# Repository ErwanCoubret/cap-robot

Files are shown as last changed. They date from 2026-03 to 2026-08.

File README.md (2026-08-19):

# CAP - ROBOT BODY

## OVERVIEW

Cap is the AI-powered assistant of [Flots app](https://flots.app). Its main purpose is to help users with their daily tasks and provide a friendly interface for interacting with the app.

The goal of this project is to give a physical form to Cap, allowing users to interact with it in a more natural and engaging way.

## RASPBERRY PI SETUP

From total scratch with a fresh Raspberry Pi OS light installation

### 1. Global updates and dependencies

```bash
sudo apt update && sudo apt upgrade -y
sudo apt install git-all -y
ssh-keygen -t ed25519 -C "your_email@example.com"
cat ~/.ssh/id_ed25519.pub
```

Copy the output of the last command and add it to your GitHub account (Settings > SSH and GPG keys > New SSH key)

Allow SSH access to the Raspberry Pi from your computer:

```sh
sudo systemctl enable --now ssh
```

SSH command on your remote computer:

```sh
ssh cap@192.168.10.127 # password: cap
```

### 2. Specific dependencies for the project

```bash
sudo apt install python3-pip python3-venv
```

#### Clone the repository

```bash
git clone
```

#### Install ai-camera dependencies

Read the [ai-camera README](./ai-camera/README.md) for instructions on how to set up the camera and load models.

#### Control eyes via serial

Read the [eyes README](./eyes/README.md) for instructions on how to control the eyes via serial protocol.

## Components

### Overview

```mermaid
flowchart TD
    RPiPSU[🔌 Raspberry Pi Power Supply]
    SPower[🔌 Servos Power Supply Adapter \nstored in head to centralize power distribution]

    RPiPSU --> HEAD
    SPower --> HEAD

    HEAD[== 🤖 HEAD ==]
    NECK[== 🦒 NECK ==]
    BODY[== 🧍 BODY ==]
    
    HEAD -- GPIO Control + Power --> NECK
    HEAD -- HDMI Video --> BODY
    HEAD -- Audio --> BODY
    
    subgraph HEAD
        RPi5[🖥️ Raspberry Pi 5\nmain control, face detection, interface, agent system]

        ESP32[🎮 ESP32]
        Cam[📷 AI Camera]
        Display1[📺 Rounded Display 1\n240x240]
        Display2[📺 Rounded Display 2\n240x240]

        MIC[🎤 Microphone]
    end
    
    subgraph NECK
        S1[⚙️ Servo 1 \nHorizontal]
        S2[⚙️ Servo 2 \nVertical]
    end
    
    subgraph BODY
        Disp[📺 Tactile Display]
        Spkr[🔊 Speaker]
    end
    
```

### List

#### HEAD

| Title | Description | Links |
|---|---|---|
| Raspberry Pi 5 8GB | Main computing unit | [Specs](./DOCS/RASPBERRY_PI_5.pdf) |
| Raspberry Pi AI Camera with Sony IMX500 | Vision module | [Specs](./DOCS/RASPBERRY_PI_CAMERA.pdf) |
| ESP32-WROOM-32 Development Board USB-C (NodeMCU-32S) | Microcontroller for eye displays | [Datasheet](./DOCS/esp32-wroom-32d_esp32-wroom-32u_datasheet_en.pdf) |
| 2 x GC9A01 1.28" TFT LCD Display Module | Eye displays, 240x240 pixels | [Datasheet](./DOCS/GC9A01%20DataSheet%20V1.1.pdf) |
| AGPTEK Microphone Module (AC02B Mini Lapel Microphone) | Audio input | - |

**Connections**

- USB-C to USB-C cable -> Raspberry Pi 5 Charging port
- Raspberry Pi Power Supply -> USB-C to USB-C cable, Female port
- USB-C to USB-A cable -> ESP32 USB-C port to Raspberry Pi USB-A port
- Wires to connect the GC9A01 displays to the ESP32

**Diagram**

```mermaid
flowchart TD
    RPi5[🖥️ Raspberry Pi 5]
    Camera[📷 AI Camera\nSony IMX500]
    ESP32[🎮 ESP32-WROOM-32]
    Display1[📺 GC9A01 Display 1\n240x240]
    Display2[📺 GC9A01 Display 2\n240x240]
    Mic[🎤 AC02B Microphone]
    RPiPSU[🔌 Raspberry Pi Power Supply]
    
    RPiPSU -- USB-C --> RPi5
    ESP32 -- USB-C to USB-A --> RPi5
    Camera -- CSI --> RPi5
    ESP32 -- GPIO/Wires --> Display1
    ESP32 -- GPIO/Wires --> Display2
    Mic -- USB/Audio --> RPi5
```

#### NECK

| Title | Description | Links |
|---|---|---|
| 2 x SG90 180° Servo Motor | Head movement control, GPIO controlled | - |
| Elegoo 545043 Breadboard Power Supply (5V/3.3V) | Power distribution, stored in head | [Specs](./DOCS/breadboard-datasheet.pdf) |
| AUKRU 5V/3A Power Supply Adapter | Power supply for breadboard | - |

**Connections:**
- Power Supply 5V/3A -> Breadboard Power Supply
- Wires to connect the SG90 servos to the Breadboard Power Supply and Raspberry Pi GPIO

**Diagram**

```mermaid
flowchart TD
    RPi5[🖥️ Raspberry Pi 5]
    Servo1[⚙️ SG90 Servo 1]
    Servo2[⚙️ SG90 Servo 2]
    BPS[🔌 Breadboard Power Supply\n545043]
    
    BPS -- 5V Power --> Servo1
    BPS -- 5V Power --> Servo2
    RPi5 -- GPIO Control --> Servo1
    RPi5 -- GPIO Control --> Servo2
```

#### BODY

| Title | Description | Links |
|---|---|---|
| MPI5008-5 inch 800x480 Tactile LCD Display Module | Main display with touch | [LCD Wiki](https://www.lcdwiki.com/5inch_HDMI_Displayn), [LCD Wiki Alt](https://www.lcdwiki.com/5inch_HDMI_Display) |
| Speaker (TBD) | Audio output | - |

**Connections**
- micro HDMI to HDMI cable -> Raspberry Pi micro HDMI port to Display Module HDMI port
- Wires to connect the Display Module (alimentation, tactile) to the Raspberry Pi GPIO

**Diagram**
```mermaid
flowchart TD
    RPi5[🖥️ Raspberry Pi 5]
    Display[📺 MPI5008-5in Display\n800x480]
    Speaker[🔊 Speaker\nTBD]
    
    RPi5 -- micro HDMI --> Display
    RPi5 -- GPIO/Touch --> Display
    RPi5 -- Audio --> Speaker
```

### 3D Models

TBD

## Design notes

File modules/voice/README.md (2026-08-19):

# Voice

Audio input/output for the robot. Mic is wired and verified; speaker is TBD
(see root [README.md](../../README.md)).

| Hardware | Role | Interface |
| --- | --- | --- |
| AGPTEK AC02B (lapel mic) | Audio input | USB |
| Speaker (TBD) | Audio output | not yet connected |

---

## 1. Verify the mic is detected

```bash
arecord -l
```

Expected: a USB card, e.g.

```
card 2: Device [USB PnP Sound Device], device 0: USB Audio [USB Audio]
```

If nothing lists, it's a USB/cable problem — nothing downstream can work.

List the ALSA device names actually usable with `-D`:

```bash
arecord -L
```

The one to use is `plughw:CARD=Device,DEV=0` (handles sample-rate/format
conversion; `hw:...` is stricter and can reject formats the app requests).

---

## 2. Check gain and mute state

```bash
amixer -c 2 contents
```

(replace `2` with the card number from `arecord -l`)

Reference state on this robot:

| Control | Value |
| --- | --- |
| `Mic Capture Switch` | `on` |
| `Mic Capture Volume` | `16` (max, 23.81dB) |
| `Auto Gain Control` | `on` |

If the switch is off or volume is 0, set it:

```bash
amixer -c 2 sset 'Mic' 16 unmute
```

---

## 3. Record a test clip

```bash
arecord -D plughw:CARD=Device,DEV=0 -f S16_LE -r 16000 -d 4 /tmp/mictest.wav
```

`-d 4` is the duration in seconds. Play it back on the Pi (if a speaker is
connected) with:

```bash
aplay /tmp/mictest.wav
```

### Check it actually captured signal, not silence

A clip can be zero-length-valid but pure noise floor if the mic is unplugged
at the connector, muted, or facing away. Check peak/RMS instead of trusting
the recording completed without error:

```bash
python3 test-codes/record_test.py --seconds 4
```

Talk or clap when it says to. Output:

```
peak=<n> rms=<n> (max=32767)
```

Peak below ~300 with someone actively talking near the mic means no usable
signal — check placement, gain (section 2), or cable, in that order.

---

## 4. Troubleshooting

| Symptom | Cause |
| --- | --- |
| `arecord -l` shows no card | USB mic unplugged or dead cable |
| `arecord` exits with `No such device` | Wrong `-D` value — re-check `arecord -L` |
| Recording succeeds but peak stays near 0 while talking | Mic muted (`Mic Capture Switch`) or gain at 0 |
| Peak is low but not zero, room is quiet | Normal — ambient noise floor, not a fault |
| `Device or resource busy` | Another process holds the device — `fuser /dev/snd/*` to find it |

---

## 5. Verified state

Measured on this robot (Raspberry Pi 5, `cap@192.168.10.127`):

- Mic enumerated: `card 2: Device [USB PnP Sound Device], device 0: USB Audio`
- `Mic Capture Switch: on`, `Mic Capture Volume: 16` (max), `Auto Gain Control: on`
- `arecord -D plughw:CARD=Device,DEV=0 ...` records without error, correct
  file size for the requested duration/rate
- Signal level pending a live talk/clap test near the mic to confirm
  capture, beyond ambient-noise-floor readings

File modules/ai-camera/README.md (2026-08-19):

# AI Camera IMX500

The Sony IMX500 is a camera module with an AI accelerator inside the sensor itself. The neural network runs on the sensor die, so inference costs the
Raspberry Pi almost no CPU: the Pi only reads the resulting tensors out of the
frame metadata.

https://docs.ultralytics.com/fr/integrations/sony-imx500

This directory holds the face tracker that drives the robot's eyes:
camera → face detection on the sensor → screen coordinates → ESP32 over serial.

```
IMX500 sensor            Raspberry Pi 5              ESP32 + GC9A01
[ YOLOv8n-face ]  --->  [ face_tracker.py ]  --->   [ eyes_serial.ino ]
   NPU, ~11 fps          decode + mapping            "x,y\n" @ 115200
```

---

## 1. Install

On the Raspberry Pi 5:

```bash
sudo apt update
sudo apt install -y python3-picamera2 imx500-all imx500-tools python3-opencv
sudo reboot
```

- `imx500-all` pulls in the sensor firmware and the stock model set
- `imx500-tools` provides `imx500-package`, needed to pack a custom model
- `python3-picamera2` is the capture and inference API
- `python3-opencv` is only needed for the visualiser, not for the tracker

`pyserial` ships with Raspberry Pi OS; check with `python3 -c "import serial"`.

> The `modlib` library (`aitrios-rpi-application-module-library`) is **not**
> required. It is a higher-level wrapper; everything here uses `picamera2`
> directly, which is already packaged and avoids a `--break-system-packages`
> pip install.

### Clone the repository on the Pi

```bash
git clone git@github.com:ErwanCoubret/cap-robot.git ~/cap-robot
```

---

## 2. Verify the hardware before running anything

Run these three checks in order. Each one isolates a different failure, so a
red result tells you exactly where to look.

**Camera detected on the CSI bus:**

```bash
rpicam-hello --list-cameras
```

Expected: `0 : imx500 [4056x3040 10-bit RGGB] (/base/axi/pcie@.../imx500@1a)`.
If the camera is missing, it is a cable or power problem — nothing downstream
can work.

**Sensor stack installed:**

```bash
dpkg -l | grep -E "imx500|picamera2"
```

Reference state on this robot:

| Package | Version |
| --- | --- |
| `imx500-all` | 1.12.0-1 |
| `imx500-firmware` | 0.FF23+3 |
| `imx500-models` | 1:1.0.0-1 |
| `imx500-tools` | 0~20241022+2-1+trixie |
| `python3-picamera2` | 0.3.37-1 |

**ESP32 present and writable:**

```bash
ls -l /dev/ttyUSB*
udevadm info -q property -n /dev/ttyUSB0 | grep ID_MODEL_FROM_DATABASE
groups | grep dialout
```

The board uses a CH340 bridge (`1a86:7523`), so it appears as `/dev/ttyUSB0`,
**not** `/dev/ttyACM0`. Your user must be in `dialout`; otherwise:

```bash
sudo usermod -aG dialout $USER   # log out and back in
```

### Check what the camera is actually looking at

Do this before debugging any "the model detects nothing" problem. A model that
returns zero detections because the camera faces a wall looks identical to a
broken model.

```bash
rpicam-jpeg -o /tmp/frame.jpg -t 2000
```

Then open `/tmp/frame.jpg` and confirm a face is in frame.

### Check the serial link on its own

This writes three positions straight to the ESP32, with no camera involved. The
pupil should jump left, right, then back to centre.

```bash
python3 - <<'EOF'
import serial, time
ser = serial.Serial("/dev/ttyUSB0", 115200, timeout=1, write_timeout=1)
time.sleep(2)                     # let the board finish rebooting
for p in ["60,120", "180,120", "120,120"]:
    ser.write((p + "\n").encode())
    print("sent", p)
    time.sleep(1.2)
ser.close()
EOF
```

If nothing moves, the fault is on the ESP32 side (wrong sketch flashed, wrong
baud rate), not on the camera side.

---

## 3. Put the face model on the sensor

The model is [YOLOv8n-face by lindevs](https://github.com/lindevs/yolov8-face),
already exported to IMX format in `models/yolov8n-face-lindevs_imx_model/`.

### Re-exporting from a `.pt` (only if you change the model)

```bash
yolo export model=models/yolov8n-face-lindevs.pt format=imx
```

This runs post-training quantisation and produces a folder containing
`packerOut.zip`, `labels.txt` and `dnnParams.xml`. Export on a desktop, not on
the Pi — it needs PyTorch and the compression toolkit.

`model-creation/model-compression.py` does the same quantisation by hand with
Sony's Model Compression Toolkit, using the photos in `model-creation/images/`
as the calibration set. It is only needed when the Ultralytics export gives
poor accuracy and the calibration data has to match the robot's real scene.

### Pack it into sensor firmware

`packerOut.zip` cannot be loaded directly — it has to become a `.rpk`:

```bash
cd ~/cap-robot/ai-camera/models/yolov8n-face-lindevs_imx_model
imx500-package -i packerOut.zip -o rpk
```

This writes `rpk/network.rpk` (3.0 MB). Check the memory report next to it:

```json
"Memory Usage": "7,06MB", "Total Memory Available On Chip": "8,00MB",
"Memory Utilization": "89%", "Fit In Chip": true
```

`Fit In Chip: false` means the model is too big for the sensor's 8 MB and will
never load, whatever you do afterwards.

`rpk/` is generated, not committed — regenerate it after every re-export.

---

## 4. Run the tracker

```bash
cd ~/cap-robot

python3 ai-camera/face_tracker.py                  # normal run, /dev/ttyUSB0
python3 ai-camera/face_tracker.py --verbose        # also print what is sent
python3 ai-camera/face_tracker.py --no-serial      # camera only, no ESP32
python3 ai-camera/face_tracker.py --threshold 0.6  # stricter detection
```

The first start uploads ~3 MB of network firmware into the sensor and takes
about 45 seconds, with a progress bar. Later starts reuse it and are fast.

`--no-serial` is the safe way to debug: it prints the coordinates it *would*
send, and never opens the serial port.

### Visualising what the robot sees

`face_tracker_visualizer.py` runs the same detection and drives the eye exactly
like the tracker, but also opens a window the size of the eye screen (240x240)
showing the camera view, the detected face and the position being sent.

```bash
cd ~/cap-robot/ai-camera
python3 face_tracker_visualizer.py --scale 2      # window doubled, eye driven
python3 face_tracker_visualizer.py --no-serial    # preview only
```

`q` or `Esc` quits. The window must be on the Pi's own display; over SSH,
prefix the command with `DISPLAY=:0`.

The preview is mirrored, like a selfie, which puts it in the same frame of
reference as the coordinates sent to the eye — so the red dot is drawn at the
transmitted position directly. If the dot sits on the face, the mapping is
correct. The grey circle marks how far the pupil can actually look: past it,
the firmware clamps to the edge.

Only one process can hold the IMX500 at a time. `Device or resource busy` on
startup means another run is still alive — wait for it, or `pkill -f
face_tracker`.

### Why the rates are capped

The sensor runs at 15 fps and the serial output at 20 Hz on purpose. The ESP32
reads one line per render loop; sending faster overflows its RX buffer and the
eye stutters or freezes. The firmware smooths motion on its side
(`SMOOTHING = 0.08`), so a higher rate would not look better anyway.

When no face has been visible for 1.5 s the tracker sends the centre position
once, then stays quiet until a face returns.

---

## 5. Reading the model output

This is the part that is not documented upstream and cost the most time, so it
is worth writing down.

The Ultralytics IMX export bakes NMS into the network. The sensor returns four
tensors, already sorted by confidence:

| Tensor | Shape | Meaning |
| --- | --- | --- |
| 0 | `(1, 300, 4)` | boxes |
| 1 | `(1, 300)` | scores |
| 2 | `(1, 300)` | class ids (always 0 — single class, `face`) |
| 3 | `(1, 1)` | number of valid detections |

Two traps, both confirmed by overlaying a box on a captured frame:

1. **Boxes are `[x0, y0, x1, y1]`** — not picamera2's usual `(y, x)` ordering.
2. **Boxes are absolute pixels in the model's square 640x640 input.** The
   camera stream is 640x480, so it is letterboxed with 80 px bars top and
   bottom. Subtract the padding before normalising:
   `img_y = box_y - 80`.

Consequently `imx500.convert_inference_coords()` **must not be used here**: it
assumes normalised boxes and returns six-digit garbage. `to_screen()` in
`face_tracker.py` removes the padding and normalises by hand.

The X axis is mirrored on purpose (`1.0 - cx`) so that when the person moves to
their right, the eye looks the same way they do.

---

## 6. Troubleshooting

| Symptom | Cause |
| --- | --- |
| Scores are all exactly `0.0` | No face in frame. Save a JPEG and look at it before suspecting the model. |
| Box values look plausible but scores are 0 | The box tensor shares its `l2Offset` with the input tensor, so it aliases image data. Trust the score, not the box. |
| Coordinates are six digits | `convert_inference_coords()` was used. See section 5. |
| Coordinates are sent but the pupil does not move | ESP32 side: wrong sketch flashed, or wrong baud rate. The sketch must be at 115200 and map to a 240x240 round screen. |
| `Permission denied` on `/dev/ttyUSB0` | User not in `dialout`. |
| Nothing on `/dev/ttyACM0` | Wrong device — the CH340 bridge enumerates as `/dev/ttyUSB0`. |
| `Fit In Chip: false` | Model too large for the sensor's 8 MB. |

---

## 7. Verified state

Measured on this robot (Raspberry Pi 5, `cap@192.168.10.127`):

- Camera enumerated: `imx500 [4056x3040 10-bit RGGB]`
- Face model packed to `network.rpk`, 89% chip memory, `Fit In Chip: true`
- Inference running at ~11 fps, **0.82 confidence on a live face, every frame**
- Serial writes accepted at 115200 baud on `/dev/ttyUSB0`
- Full loop confirmed end to end: camera → detection → mapping → ESP32, with
  the pupil following the face

## References

- [IMX500 converter documentation (Sony AITRIOS)](https://developer.aitrios.sony-semicon.com/en/docs/raspberry-pi-ai-camera/imx500-converter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)
- [Ultralytics IMX500 integration](https://docs.ultralytics.com/integrations/sony-imx500/#software-prerequisites)

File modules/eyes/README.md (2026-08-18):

# 👁️ Animated Eye Project (ESP32 + Round GC9A01 Display)

This project displays an animated eye (moving pupil + eyelid blinking) on a round GC9A01 TFT LCD screen, driven by an ESP32 microcontroller.

The render engine is optimized for maximum smoothness (60 FPS) with no flicker, while avoiding the memory crashes typical of the ESP32 by using a **Mini-Canvas**.

Two sketches are included:

* **`loop_eyes/`** — standalone demo, pupil cycles through fixed waypoints automatically.
* **`eyes_serial/`** — same render engine, but pupil target is driven live over serial (e.g. from a Raspberry Pi).

---

## 🛠️ Required Hardware

* **1x** ESP32 dev board (30-pin model)
* **1x** 1.28" round TFT LCD screen (GC9A01 driver)
* Jumper wires

---

## 🔌 Wiring (Pinout)

To guarantee max display speed, we use the ESP32's **Hardware SPI**. The screen pins must be connected to the board's dedicated hardware pins:

| GC9A01 Screen Pin | ESP32 Pin (Silkscreen) | Function |
| :--- | :--- | :--- |
| **VCC** | **3V3** | Power (3.3V) |
| **GND** | **GND** | Ground |
| **SCL / SCK** | **D18** | SPI Clock (Hardware SPI) |
| **SDA / MOSI** | **D23** | SPI Data (Hardware SPI) |
| **DC** | **D2** | Data / Command |
| **CS** | **D5** | Chip Select |
| **RST / RES** | **D4** | Reset |
| **BLK / BL** | **3V3** | Backlight (*Required — screen stays black without it*) |

---

## 💻 Setup & Requirements (Arduino IDE)

1. **Board configuration:** In Arduino IDE, select `Tools` > `Board` > **ESP32 Dev Module**.
2. **Required libraries:** Open the Library Manager (`Ctrl+Shift+I` or `Sketch > Include Library > Manage Libraries`) and install:
   * **Adafruit GFX Library**
   * **Adafruit GC9A01A**

---

## 🧠 How the Code Works

* **Hardware SPI:** By declaring only 3 pins (`TFT_CS`, `TFT_DC`, `TFT_RST`) in the display constructor, the ESP32 is forced to use its ultra-fast hardware SPI link (wired to pins D18 and D23).
* **The Mini-Canvas (128x128):** Instead of saturating RAM with a full 240x240 pixel buffer (which causes `StoreProhibited` crashes), a local 32 KB buffer is used around the pupil to erase and redraw movement with zero flicker and no trailing artifacts.
* **Async timers (`millis()`):** The code has no blocking `delay()`. Pupil movement and eyelid blinking run in parallel on independent time intervals.

---

## 📡 Serial Protocol (`eyes_serial`)

Send target pupil coordinates as text over serial, one pair per line:

```
<x>,<y>\n
```

* `x`, `y` are screen coordinates (center is `120,120`).
* If the point falls outside the eye radius, it's automatically clamped back onto the boundary.
* Baud rate: **115200**. At this rate the serial link is not the bottleneck — the SPI render loop is — so 115200 is plenty even for a Raspberry Pi pushing updates at 60-100 Hz.

### Testing from a Raspberry Pi

Find the ESP32's serial port first:

```bash
ls /dev/ttyUSB* /dev/ttyACM*
```

**Option 1 — `screen` (quick, interactive)**
```bash
screen /dev/ttyUSB0 115200
```
Type `120,150` + Enter to send a target. Exit with `Ctrl-A` then `k`, confirm `y`.

**Option 2 — `minicom` (nicer UI)**
```bash
sudo apt install minicom
minicom -D /dev/ttyUSB0 -b 115200
```
Quit with `Ctrl-A` then `X`.

**Option 3 — Python + pyserial (scripted test loop)**
```bash
pip install pyserial
python3 -c "
import serial, time
s = serial.Serial('/dev/ttyUSB0', 115200, timeout=1)
time.sleep(2)  # wait for ESP32 reset after port open
while True:
    s.write(b'120,150\n')
    time.sleep(1)
    s.write(b'60,90\n')
    time.sleep(1)
"
```

> Opening the serial port resets the ESP32 (DTR toggle) — expect a ~1-2s delay before it's ready. It prints `Systeme pret !` once initialized if you read the port back.

---

## ⚙️ Customization

Key parameters can be changed directly in the source code:

* **Colors (RGB565 format):**
  * `COLOR_WHITE` (`0xFFFF`): background / eyeball.
  * `COLOR_PUPIL` (`0x2169`): pupil color (`#232B49`).
  * `COLOR_EYELID` (`0x633F`): eyelid color (`#615FFF`).
* **Animation variables:**
  * `PUPIL_RADIUS`: pupil size (e.g. `60`).
  * `SMOOTHING`: glide smoothness (e.g. `0.08` for a slow, soft movement).
  * `BLINK_INTERVAL`: time between each blink (e.g. `1600` ms).
  * `DELAY_BETWEEN_MOVES` *(loop_eyes only)*: pause between each automatic waypoint change.

---

## 🆘 Troubleshooting

* **Screen stays black:** Check that the **BLK** pin is connected to **3.3V** and that the SPI lines (D18 and D23) are correct.
* **Port-related compile error:** Make sure **ESP32 Dev Module** is selected under Arduino board types.
* **No response from `eyes_serial`:** Confirm the baud rate matches on both ends (115200) and that you're writing to the correct `/dev/ttyUSB*`/`/dev/ttyACM*` device.

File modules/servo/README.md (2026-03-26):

# Servo-motor control

Related info for the servo-motor control module.

## Hardware setup

The servo-motor is connected to the Raspberry Pi 5 as follows:

- **GPIO Pin 18** (6th pin from the top left) is used for the PWM signal to control the servo.
- The servo's power and ground are connected to the appropriate pins on the Raspberry Pi (usually 5V and GND).

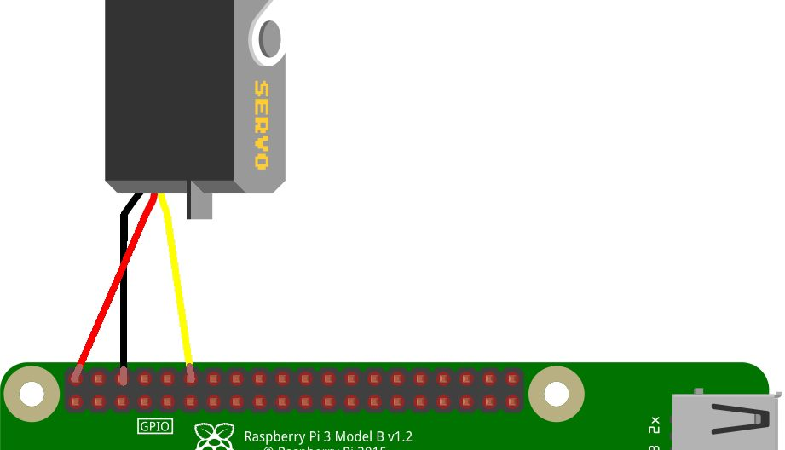
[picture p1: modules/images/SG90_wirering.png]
Servo Wiring Diagram


Source https://raspberry-pi.fr/servomoteur-raspberry-pi/ for more details on the wiring and setup

## Extreme values

With the following code, it is necessary to respect the extreme values of the servo-motor, otherwise it may be damaged.

`MAX_POS=0` and `MIN_POS=-1.8` are the limits of the servo-motor's range of motion.

```python
def set_pos(p):
  if p < -1.8 or p > 0:
    print("Value out of range [-1.8, 0]. Rejected to protect the hardware.")
    return

  # p ranges from -1.8 (left) to 0 (right)
  width = 1500 + (p * 500)

  # 1. Send PWM signal to move the servo
  lgpio.tx_pwm(h, GPIO_PIN, 50, (width / 20000.0) * 100.0)
  
  # 2. Wait for the servo to physically reach its destination
  time.sleep(0.5) 
  
  # 3. Cut the signal to prevent jitter
  lgpio.tx_pwm(h, GPIO_PIN, 0, 0)
```

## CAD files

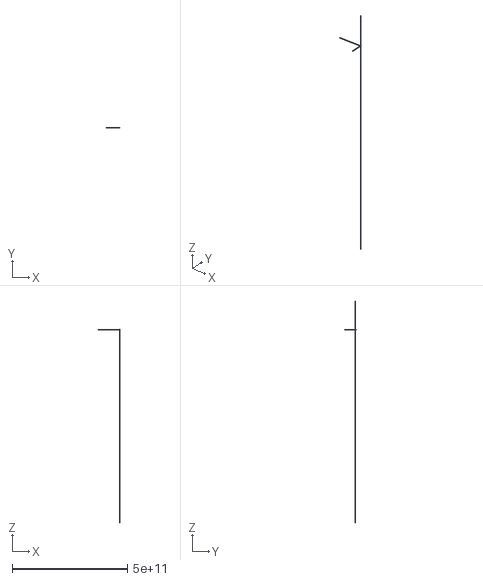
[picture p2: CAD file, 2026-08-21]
cap-3d-body/yeux mecatronic/Reference/Complete Model.stl
94940546112.0 x 50519834624.0 x 961114644480.0

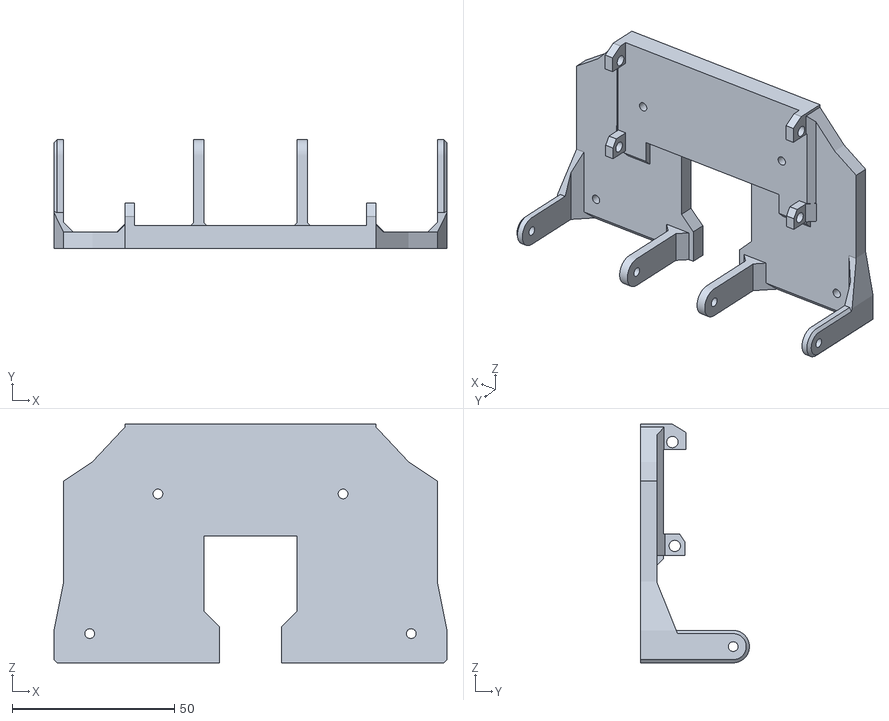
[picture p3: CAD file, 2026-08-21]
cap-3d-body/yeux mecatronic/Stl Files/Main Base.stl
121.0 x 33.5 x 73.5

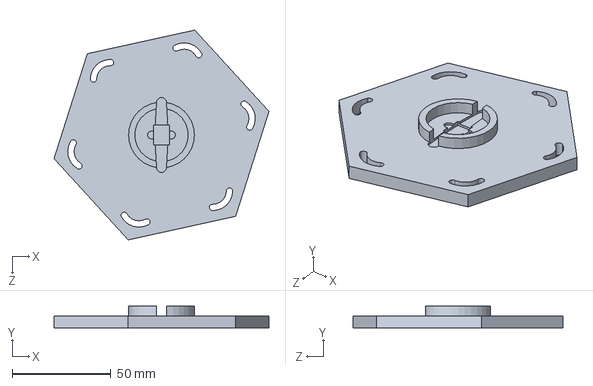
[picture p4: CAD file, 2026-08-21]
cap-3d-body/Cap/ancienne piece/socle coup.SLDPRT
109.0 x 11.0 x 106.4 mm

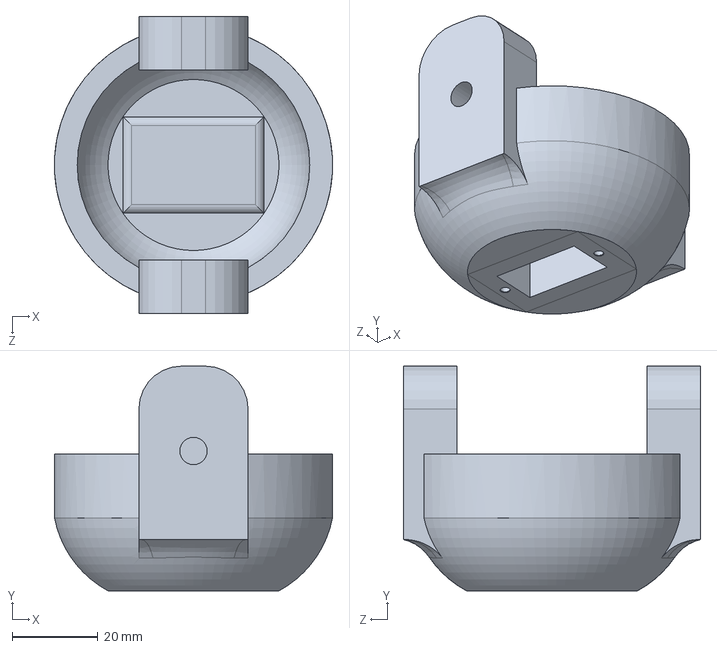
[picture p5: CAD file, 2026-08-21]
cap-3d-body/Cap/Cap VF/coup mobile lie corps.SLDPRT
64.9 x 52.5 x 69.5 mm

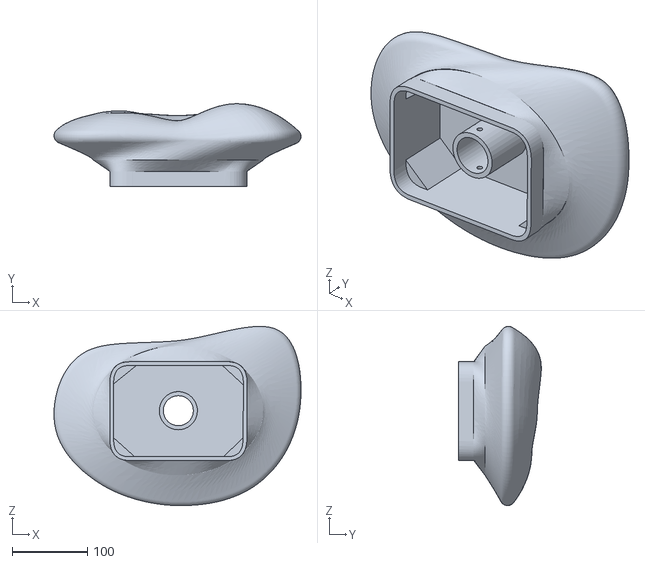
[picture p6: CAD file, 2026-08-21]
cap-3d-body/projet en stl/chapeau.STL
329.1 x 110.1 x 238.8

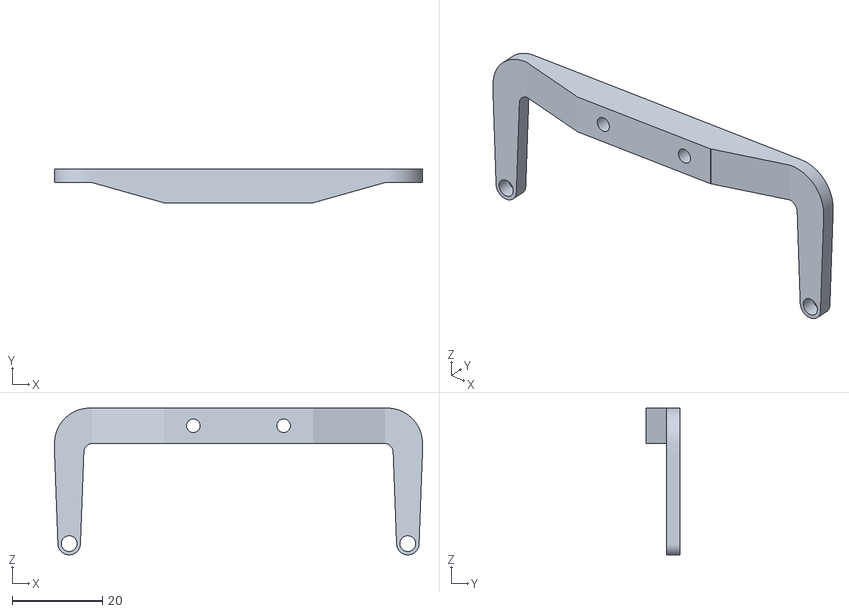
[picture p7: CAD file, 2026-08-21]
cap-3d-body/yeux mecatronic/Stl Files/Eye Holder.stl
81.5 x 7.53 x 32.5

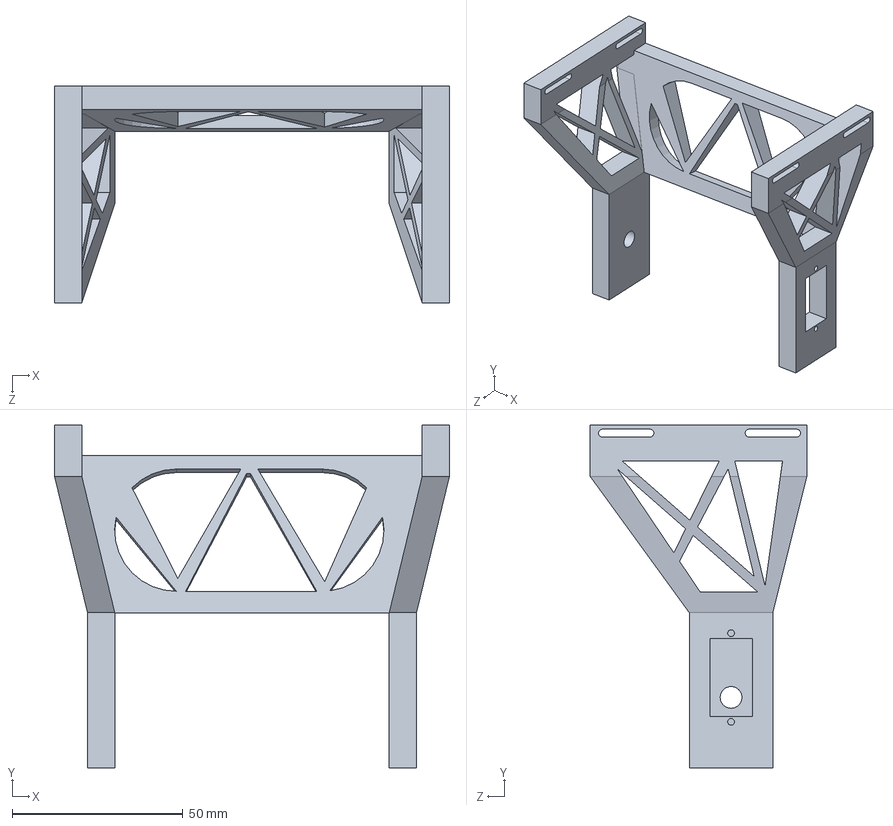
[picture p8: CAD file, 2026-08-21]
cap-3d-body/Cap/ancienne piece/coup mobile 2.SLDPRT
115.8 x 100.5 x 63.6 mm

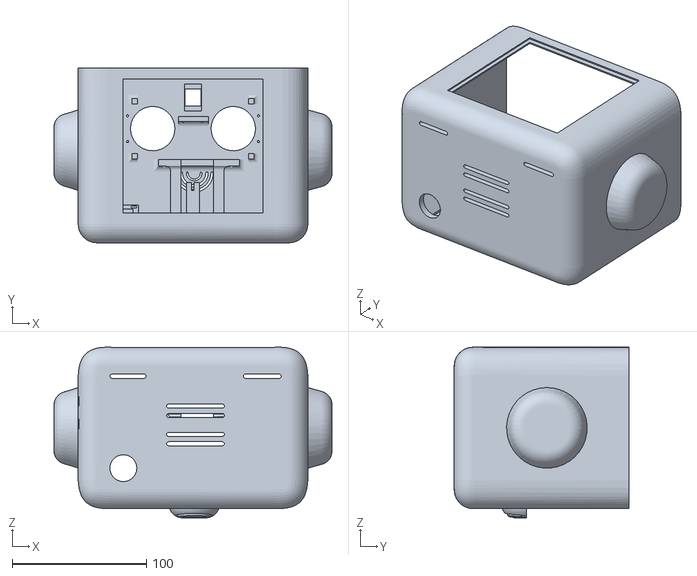
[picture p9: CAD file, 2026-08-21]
cap-3d-body/projet en stl/tete v2.STL
207.0 x 130.0 x 127.1

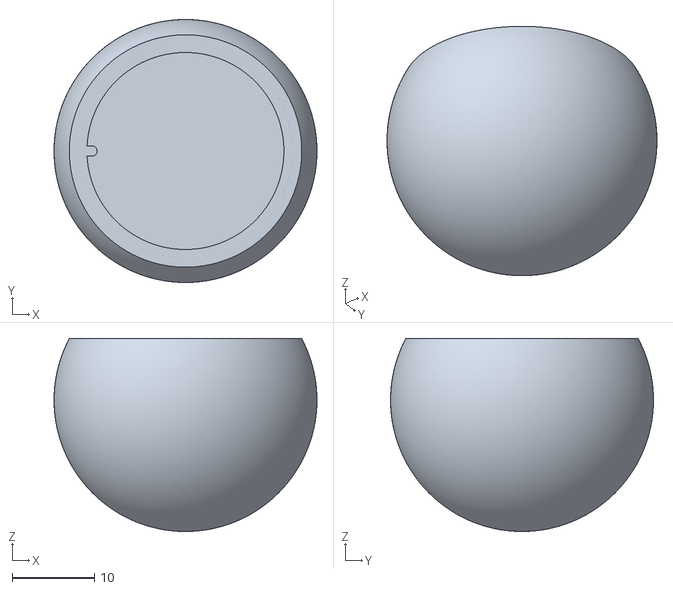
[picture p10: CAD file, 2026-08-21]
cap-3d-body/yeux mecatronic/Stl Files/PlaceHolder Eye (x2).stl
32.0 x 32.0 x 23.5

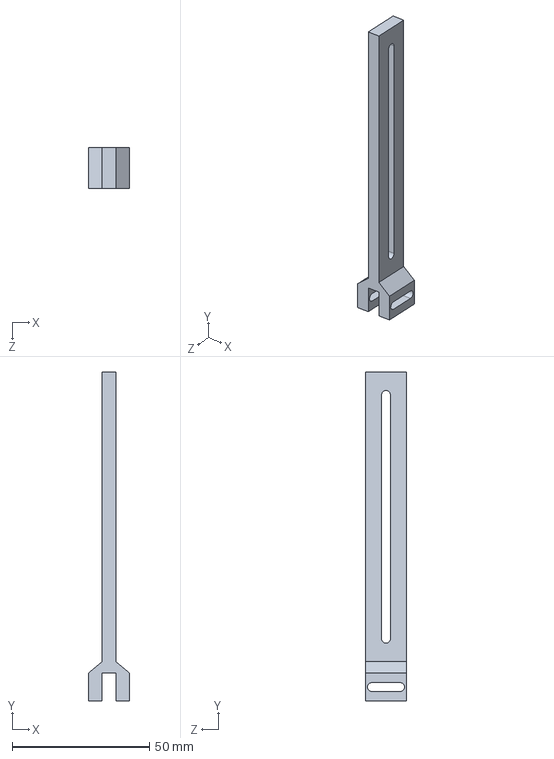
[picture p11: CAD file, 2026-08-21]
cap-3d-body/Cap/ancienne piece/raille x2.SLDPRT
15.0 x 120.0 x 15.0 mm

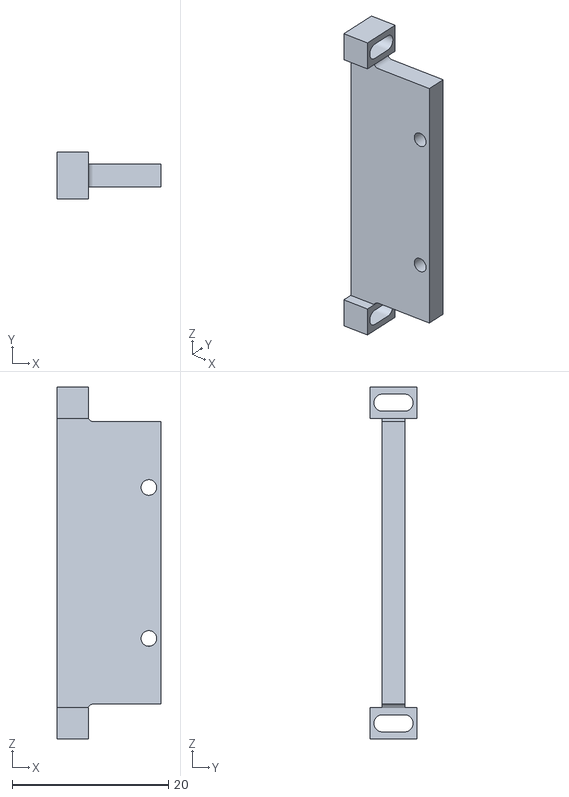
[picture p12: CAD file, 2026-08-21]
cap-3d-body/projet en stl/piece fixe oeuil x2.STL
13.3 x 6.00 x 45.0

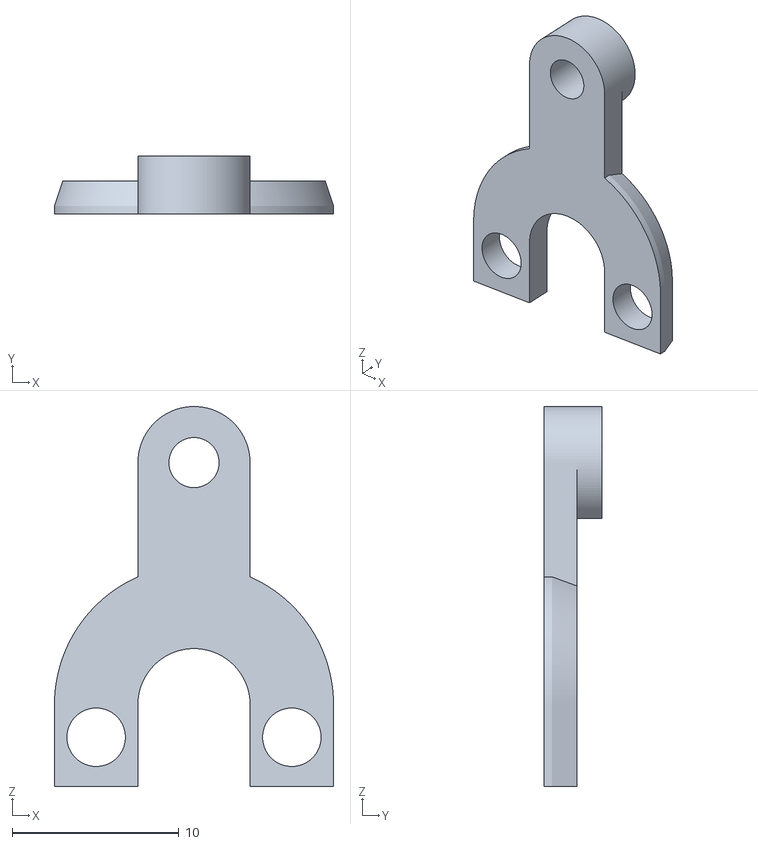
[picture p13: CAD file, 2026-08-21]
cap-3d-body/yeux mecatronic/Stl Files/Fork (x2).stl
16.7 x 3.50 x 22.8

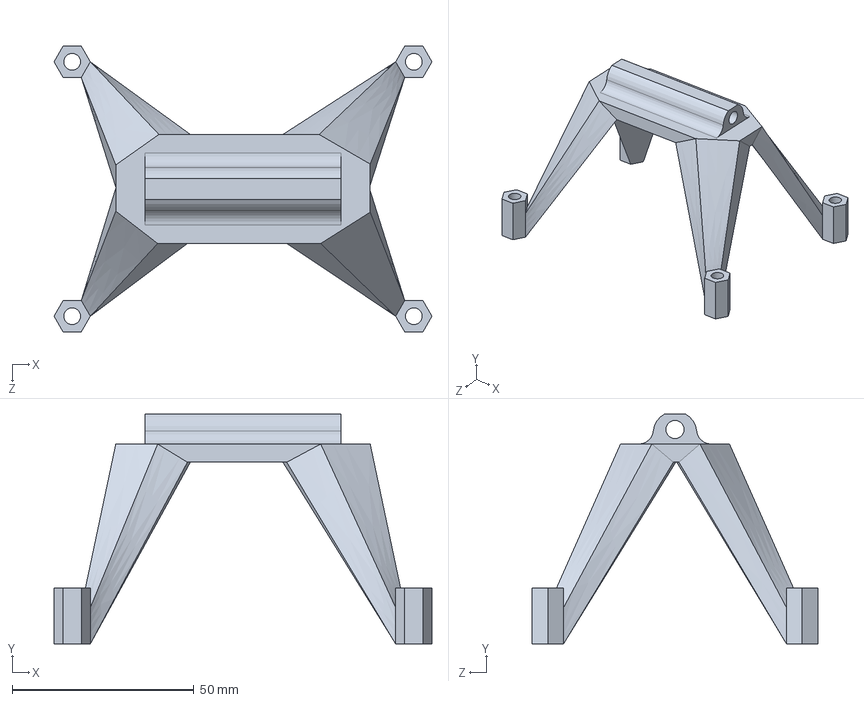
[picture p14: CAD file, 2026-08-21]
cap-3d-body/Cap/ancienne piece/piece fixe ecran 1.SLDPRT
104.0 x 63.3 x 78.7 mm

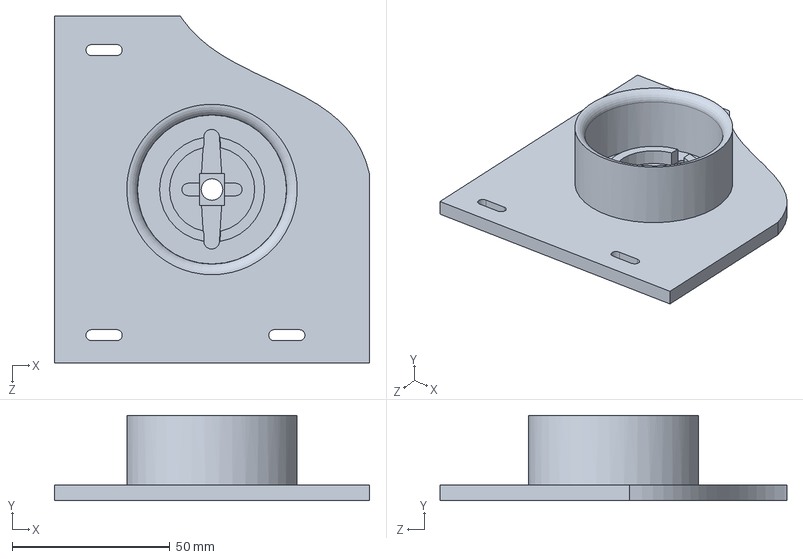
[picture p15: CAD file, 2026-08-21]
cap-3d-body/Cap/Cap VF/socle corps vers coup.SLDPRT
100.0 x 27.0 x 110.0 mm

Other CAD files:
cap-3d-body/Cap/Cap VF/chapeau.SLDPRT
cap-3d-body/Cap/Cap VF/tete.SLDPRT
cap-3d-body/projet en stl/coup mobile 2 version court.STL
cap-3d-body/Cap/ancienne piece/corps cap 1.SLDPRT
cap-3d-body/Cap/Cap VF/Porte tete.SLDPRT
cap-3d-body/Cap/Cap VF/corps cap V2.SLDPRT
cap-3d-body/Cap/Cap VF/coup mobile lie tete.SLDPRT
cap-3d-body/Cap/Cap VF/piece fixe oeuil.SLDPRT
cap-3d-body/Cap/Cap VF/porte corps.SLDPRT
cap-3d-body/Cap/Cap VF/socle tete vers coup.SLDPRT
cap-3d-body/Cap/ancienne piece/piece fixe ecran 2.SLDPRT
cap-3d-body/Cap/ancienne piece/tete 1.SLDPRT
cap-3d-body/projet en stl/corps cap 1.STL
cap-3d-body/projet en stl/corps cap V2 la bonne.STL
cap-3d-body/projet en stl/coup mobile 2 version court et ameliorer en largeur.STL
cap-3d-body/projet en stl/coup mobile 1.STL
cap-3d-body/projet en stl/piece fixe ecran 1.STL
cap-3d-body/projet en stl/piece fixe ecran 2.STL
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

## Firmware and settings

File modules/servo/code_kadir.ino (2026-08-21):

/*
 * ============================================================
 *  TEST SERVOS SG90 - Cou de robot (YAW + PITCH)
 *  Carte : Arduino Nano (ATmega328P)
 *  Moniteur série : 115200 bauds, fin de ligne "Nouvelle ligne"
 * ============================================================
 *
 *  CABLAGE
 *    Servo YAW   : signal -> D9   | Vcc -> +5V externe | GND -> GND
 *    Servo PITCH : signal -> D10  | Vcc -> +5V externe | GND -> GND
 *    IMPORTANT : la masse (GND) de l'alim externe DOIT etre reliee
 *    au GND du Nano (masse commune), sinon le signal n'est pas vu.
 *
 *  COMMANDES (taper dans le moniteur serie puis Entree)
 *    y120        -> place le YAW a 120 deg
 *    p60         -> place le PITCH a 60 deg
 *    c           -> retour au centre memorise
 *    z           -> definit la position ACTUELLE comme nouveau centre
 *    s           -> balayage lent min <-> max (test mecanique)
 *    l y 30 150  -> change les butees du yaw (min=30, max=150)
 *    l p 40 140  -> change les butees du pitch
 *    d           -> detache les servos (plus de couple, on peut bouger a la main)
 *    a           -> rattache les servos
 *    ?           -> affiche l'etat courant (a recopier dans le code)
 * ============================================================
 */

#include <Servo.h>

// ---------- Configuration ----------
const uint8_t PIN_YAW   = 8;
const uint8_t PIN_PITCH = 7;

const int STEP_DELAY = 15;   // ms par degre : plus grand = mouvement plus lent

struct Limits { int minDeg; int maxDeg; int center; };

// Valeurs de depart PRUDENTES : on evite 0 et 180 tant que la mecanique
// n'est pas validee (le SG90 force contre ses butees internes = il chauffe).
Limits limYaw   = { 0, 180, 90 };
Limits limPitch = { 0, 180, 90 };

// ---------- Etat interne ----------
Servo servoYaw, servoPitch;
int posYaw, posPitch;
bool attached = false;

// ---------- Fonctions utilitaires ----------
void attachAll() {
  servoYaw.attach(PIN_YAW);
  servoPitch.attach(PIN_PITCH);
  servoYaw.write(posYaw);
  servoPitch.write(posPitch);
  attached = true;
  Serial.println(F("[OK] Servos attaches"));
}

void detachAll() {
  servoYaw.detach();
  servoPitch.detach();
  attached = false;
  Serial.println(F("[OK] Servos detaches (couple relache)"));
}

// Deplacement degre par degre : evite les a-coups qui font sauter les pignons
void moveSlow(Servo &s, int &pos, const Limits &lim, int target, const char *name) {
  int clamped = constrain(target, lim.minDeg, lim.maxDeg);
  if (clamped != target) {
    Serial.print(F("[!] "));
    Serial.print(name);
    Serial.print(F(" limite a "));
    Serial.println(clamped);
  }
  int step = (clamped > pos) ? 1 : -1;
  while (pos != clamped) {
    pos += step;
    s.write(pos);
    delay(STEP_DELAY);
  }
  Serial.print(F("[>] "));
  Serial.print(name);
  Serial.print(F(" = "));
  Serial.println(pos);
}

void printState() {
  Serial.println(F("---------- ETAT ----------"));
  Serial.print(F("YAW   pos=")); Serial.print(posYaw);
  Serial.print(F("  min=")); Serial.print(limYaw.minDeg);
  Serial.print(F("  max=")); Serial.print(limYaw.maxDeg);
  Serial.print(F("  centre=")); Serial.println(limYaw.center);
  Serial.print(F("PITCH pos=")); Serial.print(posPitch);
  Serial.print(F("  min=")); Serial.print(limPitch.minDeg);
  Serial.print(F("  max=")); Serial.print(limPitch.maxDeg);
  Serial.print(F("  centre=")); Serial.println(limPitch.center);
  Serial.println(F("--------------------------"));
}

void sweepTest() {
  Serial.println(F("[..] Balayage YAW"));
  moveSlow(servoYaw, posYaw, limYaw, limYaw.minDeg, "YAW");
  delay(400);
  moveSlow(servoYaw, posYaw, limYaw, limYaw.maxDeg, "YAW");
  delay(400);
  moveSlow(servoYaw, posYaw, limYaw, limYaw.center, "YAW");

  Serial.println(F("[..] Balayage PITCH"));
  moveSlow(servoPitch, posPitch, limPitch, limPitch.minDeg, "PITCH");
  delay(400);
  moveSlow(servoPitch, posPitch, limPitch, limPitch.maxDeg, "PITCH");
  delay(400);
  moveSlow(servoPitch, posPitch, limPitch, limPitch.center, "PITCH");
  Serial.println(F("[OK] Balayage termine"));
}

// ---------- Traitement des commandes ----------
void handleCommand(String cmd) {
  cmd.toLowerCase();
  char c = cmd.charAt(0);
  String arg = cmd.substring(1);
  arg.trim();

  switch (c) {
    case 'y':
      if (arg.length()) moveSlow(servoYaw, posYaw, limYaw, arg.toInt(), "YAW");
      else Serial.println(F("[X] usage: y<angle>  ex: y120"));
      break;

    case 'p':
      if (arg.length()) moveSlow(servoPitch, posPitch, limPitch, arg.toInt(), "PITCH");
      else Serial.println(F("[X] usage: p<angle>  ex: p60"));
      break;

    case 'c':
      moveSlow(servoYaw, posYaw, limYaw, limYaw.center, "YAW");
      moveSlow(servoPitch, posPitch, limPitch, limPitch.center, "PITCH");
      break;

    case 'z':
      limYaw.center = posYaw;
      limPitch.center = posPitch;
      Serial.println(F("[OK] Nouveau centre memorise"));
      printState();
      break;

    case 's':
      sweepTest();
      break;

    case 'd':
      detachAll();
      break;

    case 'a':
      attachAll();
      break;

    case 'l': {
      char buf[40];
      char j;
      int a, b;
      cmd.toCharArray(buf, sizeof(buf));
      if (sscanf(buf, "l %c %d %d", &j, &a, &b) == 3 && a < b) {
        a = constrain(a, 0, 180);
        b = constrain(b, 0, 180);
        if (j == 'y') { limYaw.minDeg = a;  limYaw.maxDeg = b; }
        else          { limPitch.minDeg = a; limPitch.maxDeg = b; }
        Serial.println(F("[OK] Butees mises a jour"));
        printState();
      } else {
        Serial.println(F("[X] usage: l y 30 150"));
      }
      break;
    }

    case '?':
      printState();
      break;

    default:
      Serial.println(F("[X] Commande inconnue (tape ? pour l'etat)"));
  }
}

// ---------- Setup / Loop ----------
void setup() {
  Serial.begin(115200);
  while (!Serial) { ; }

  // On demarre AU CENTRE, jamais aux extremes
  posYaw   = limYaw.center;
  posPitch = limPitch.center;
  attachAll();

  Serial.println();
  Serial.println(F("=== TEST SERVOS SG90 - YAW / PITCH ==="));
  Serial.println(F("Commandes : y<deg> p<deg> c z s d a ? | l y 30 150"));
  printState();
}

void loop() {
  if (Serial.available()) {
    String line = Serial.readStringUntil('\n');
    line.trim();
    if (line.length() > 0) handleCommand(line);
  }
}

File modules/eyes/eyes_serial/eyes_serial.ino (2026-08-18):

#include <SPI.h>
#include <Adafruit_GFX.h>
#include <Adafruit_GC9A01A.h>

// Broches ESP32 (Mode Hardware SPI Ultra-Rapide)
#define TFT_CS   5
#define TFT_DC   2
#define TFT_RST  4
Adafruit_GC9A01A tft(TFT_CS, TFT_DC, TFT_RST);

// Création du "Mini-Canvas" de 128x128 pixels (32 Ko)
GFXcanvas16 miniCanvas(128, 128);

// Couleurs
#define COLOR_WHITE  0xFFFF  // Blanc total (Globe)
#define COLOR_PUPIL  0x2169  // Bleu foncé #232B49 (Pupille)
#define COLOR_EYELID 0x633F  // Violet #615FFF (Paupières)

// Dimensions
const int CENTER_X = 120;
const int CENTER_Y = 120;
const int PUPIL_RADIUS = 60;

// Variables de position de la pupille
float currentX = 120.0;
float currentY = 120.0;
float targetX = 120.0;
float targetY = 120.0;

float lastX = 120.0;
float lastY = 120.0;

// Mouvement lent et doux
const float SMOOTHING = 0.08;

// --- TIMER CLIGNEMENT ---
unsigned long lastBlinkTime = 0;
const unsigned long BLINK_INTERVAL = 3000;      // Clignement toutes les 1.6s

// --- VARIABLES DU CLIGNEMENT ---
bool isBlinking = false;
bool isClosing = false;
float lidProgress = 0.0; // De 0.0 (ouvert) à 1.0 (fermé)
int lastLidY = 0;

void setup() {
  Serial.begin(115200);
  tft.begin();
  tft.setRotation(0);

  if (!miniCanvas.getBuffer()) {
    Serial.println("ERREUR CRITIQUE : RAM insuffisante !");
    while(1) delay(100);
  }

  // Affichage initial
  tft.fillScreen(COLOR_WHITE);
  tft.fillCircle(CENTER_X, CENTER_Y, PUPIL_RADIUS, COLOR_PUPIL);

  Serial.println("Systeme pret ! Mode Mini-Canvas actif (Serial + Clignement).");
}

void checkSerial() {
  if (Serial.available() > 0) {
    String input = Serial.readStringUntil('\n');
    input.trim();
    int commaIndex = input.indexOf(',');

    if (commaIndex > 0) {
      int inX = input.substring(0, commaIndex).toInt();
      int inY = input.substring(commaIndex + 1).toInt();

      int dx = inX - CENTER_X;
      int dy = inY - CENTER_Y;
      float distance = sqrt(dx * dx + dy * dy);
      int maxDist = 120 - PUPIL_RADIUS;

      if (distance > maxDist) {
        targetX = CENTER_X + (dx / distance) * maxDist;
        targetY = CENTER_Y + (dy / distance) * maxDist;
      } else {
        targetX = inX;
        targetY = inY;
      }
    }
  }
}

void loop() {
  unsigned long now = millis();

  checkSerial();

  // 1. DECLENCHEMENT DU CLIGNEMENT (Indépendant)
  if (!isBlinking && (now - lastBlinkTime >= BLINK_INTERVAL)) {
    isBlinking = true;
    isClosing = true;
    lidProgress = 0.0;
    lastBlinkTime = now;
  }

  // 2. ANIMATION DU CLIGNEMENT
  if (isBlinking) {
    if (isClosing) {
      lidProgress += 0.12; // Vitesse de fermeture
      if (lidProgress >= 1.0) {
        lidProgress = 1.0;
        isClosing = false; // Commence à rouvrir
      }
    } else {
      lidProgress -= 0.10; // Vitesse d'ouverture
      if (lidProgress <= 0.0) {
        lidProgress = 0.0;
        isBlinking = false; // Clignement terminé
      }
    }
  }

  // 120 pixels est la moitié de l'écran (fermeture totale au centre)
  int curLidY = (int)(lidProgress * 120);

  // 3. GLISSEMENT DE LA PUPILLE
  currentX += (targetX - currentX) * SMOOTHING;
  currentY += (targetY - currentY) * SMOOTHING;

  int curX_int = (int)currentX;
  int curY_int = (int)currentY;
  int lastX_int = (int)lastX;
  int lastY_int = (int)lastY;

  // 4. MOTEUR DE RENDU HYBRIDE (Delta Redraw + Mini-Canvas)
  if (curX_int != lastX_int || curY_int != lastY_int || curLidY != lastLidY) {

    // --- ETAPE A : Dessiner les paupières directement sur l'écran ---
    if (curLidY != lastLidY) {
      if (curLidY > lastLidY) {
        // Fermeture
        tft.fillRect(0, lastLidY, 240, curLidY - lastLidY, COLOR_EYELID);
        tft.fillRect(0, 240 - curLidY, 240, curLidY - lastLidY, COLOR_EYELID);
      } else {
        // Ouverture (on efface en blanc)
        tft.fillRect(0, curLidY, 240, lastLidY - curLidY, COLOR_WHITE);
        tft.fillRect(0, 240 - lastLidY, 240, lastLidY - curLidY, COLOR_WHITE);
      }
    }

    // --- ETAPE B : Préparer le Mini-Canvas pour la pupille ---
    int screenX = (curX_int + lastX_int) / 2 - 64;
    int screenY = (curY_int + lastY_int) / 2 - 64;

    miniCanvas.fillScreen(COLOR_WHITE);

    int localX = curX_int - screenX;
    int localY = curY_int - screenY;
    miniCanvas.fillCircle(localX, localY, PUPIL_RADIUS, COLOR_PUPIL);

    // --- ETAPE C : Superposer les paupières dans le Mini-Canvas ---
    if (curLidY > screenY) {
      int h = curLidY - screenY;
      if (h > 128) h = 128;
      miniCanvas.fillRect(0, 0, 128, h, COLOR_EYELID);
    }

    int bottomLidY = 240 - curLidY;
    if (bottomLidY < screenY + 128) {
      int localY_lid = bottomLidY - screenY;
      if (localY_lid < 0) localY_lid = 0;
      miniCanvas.fillRect(0, localY_lid, 128, 128 - localY_lid, COLOR_EYELID);
    }

    // --- ETAPE D : Envoi à l'écran ---
    tft.drawRGBBitmap(screenX, screenY, miniCanvas.getBuffer(), 128, 128);

    lastX = currentX;
    lastY = currentY;
    lastLidY = curLidY;
  }
}

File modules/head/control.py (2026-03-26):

import time
import numpy as np
import serial
import lgpio

from modlib.apps import Annotator
from modlib.devices import AiCamera
from modlib.models import COLOR_FORMAT, MODEL_TYPE, Model
from modlib.models.post_processors import pp_od_yolo_ultralytics

# ==========================================
# 1. CONFIGURATION ARDUINO (Port Série)
# ==========================================
# ⚠️ Remplace par ton vrai port (ex: /dev/ttyUSB0 ou /dev/ttyACM0)
ARDUINO_PORT = '/dev/ttyACM0' 
BAUD_RATE = 9600

try:
    arduino = serial.Serial(ARDUINO_PORT, BAUD_RATE, timeout=0.1)
    print(f"🔌 Connecté à l'Arduino sur {ARDUINO_PORT}")
except Exception as e:
    print(f"⚠️ Erreur Arduino : {e} (Le code continuera sans l'écran)")
    arduino = None

# ==========================================
# 2. CONFIGURATION SERVO (LGPIO)
# ==========================================
GPIO_PIN = 18 
CHIP = 4 
h = lgpio.gpiochip_open(CHIP)
lgpio.gpio_claim_output(h, GPIO_PIN)

current_servo_pos = -1  # Position initiale

def update_servo(p):
    """Envoie le signal PWM sans bloquer (pas de sleep, pas de coupure)"""
    # 🛠️ CORRECTION : On force la conversion en Float Python standard
    p = float(p) 
    
    if p < -1.8 or p > 0:
        return # Sécurité matérielle respectée
        
    width = 1500 + (p * 500)
    
    duty_cycle = float((width / 20000.0) * 100.0)
    
    lgpio.tx_pwm(h, GPIO_PIN, 50, duty_cycle)

# ==========================================
# 3. CONFIGURATION IA (Modlib)
# ==========================================
class YOLO(Model):
    def __init__(self):
        super().__init__(
            model_file="/home/erwan/cap-robot/ai-camera/models/yolov8n-face-lindevs_imx_model/packerOut.zip", 
            model_type=MODEL_TYPE.CONVERTED,
            color_format=COLOR_FORMAT.RGB,
            preserve_aspect_ratio=False,
        )
        try:
            self.labels = np.genfromtxt(
                "/home/erwan/cap-robot/ai-camera/models/yolov8n-face-lindevs_imx_model/labels.txt", 
                dtype=str, delimiter="\n"
            )
        except OSError:
            self.labels = ["Visage"]

    def post_process(self, output_tensors):
        return pp_od_yolo_ultralytics(output_tensors)

# ==========================================
# 4. PARAMÈTRES DE TRACKING & MAPPING
# ==========================================
# ⚠️ Remplace par la résolution réelle de ton IA (ex: 640x480)
CAM_WIDTH = 640  
CAM_HEIGHT = 480 

# Dimensions de l'écran TFT Arduino
TFT_WIDTH = 320
TFT_HEIGHT = 240

# Sensibilité du moteur (Proportionnel)
# Si le robot oscille (tremble) -> baisse cette valeur
# Si le robot est trop lent -> augmente cette valeur
KP = 0.002 

print("🤖 Initialisation de l'AI Camera (via modlib)...")
device = AiCamera(frame_rate=2) 
model = YOLO()
device.deploy(model)

print("🎯 IA déployée avec succès ! Lancement du tracking global...")
update_servo(current_servo_pos) # On centre le moteur au démarrage

last_servo_move_time = time.time()
pwm_active = False
last_sent_pos = -999.0  

try:
    with device as stream:
        for frame in stream:
            valid_detections = frame.detections[frame.detections.confidence > 0.55]
            
            # ==========================================
            # 1. GESTION DU VISAGE
            # ==========================================
            if len(valid_detections) > 0:
                
                # Ta boucle magique
                for bbox, score, class_id, _ in valid_detections:
                    x_min, y_min, x_max, y_max = bbox
                    
                    # Coordonnées Normalisées et Effet Miroir
                    cx_norm = 1.0 - ((x_min + x_max) / 2)
                    cy_norm = (y_min + y_max) / 2
                    
                    cx = cx_norm * CAM_WIDTH
                    cy = cy_norm * CAM_HEIGHT
                    
                    # --- A. YEUX ARDUINO ---
                    if arduino and arduino.is_open:
                        target_x = int((cx / CAM_WIDTH) * TFT_WIDTH)
                        target_y = int((cy / CAM_HEIGHT) * TFT_HEIGHT)
                        arduino.write(f"{target_x} {target_y}\n".encode('utf-8'))
                    
                    # --- B. TRAVELLING MOTEUR (BEAUCOUP PLUS RAPIDE) ---
                    # 🔥 Vitesse multipliée par 4 (Tu peux monter à 0.15 si c'est encore trop lent)
                    SERVO_STEP = 0.12  
                    new_pos = current_servo_pos
                    
                    if cx_norm < 0.30:
                        new_pos -= SERVO_STEP
                    elif cx_norm > 0.70:
                        new_pos += SERVO_STEP
                        
                    # 🛡️ ANTI-JITTER MATHÉMATIQUE : On arrondit à 2 décimales 
                    # pour ignorer les micro-variations invisibles du type -1.4533 vs -1.4534
                    new_pos = round(max(-1.8, min(0.0, new_pos)), 2)
                    
                    # On n'envoie le signal QUE si la position a vraiment changé
                    if new_pos != last_sent_pos:
                        current_servo_pos = new_pos
                        update_servo(current_servo_pos)
                        
                        last_sent_pos = current_servo_pos
                        last_servo_move_time = time.time() # On relance le chrono
                        pwm_active = True
                        
                        print(f"🎯 Zone: {cx_norm*100:.0f}% | ⚙️ Servo: {current_servo_pos:.2f}")
                        
                    break # On traite un seul visage par frame
            
            # ==========================================
            # 2. ANTI-JITTER MATÉRIEL (La méthode forte)
            # ==========================================
            # Si le signal est actif MAIS qu'on n'a pas bougé depuis 0.3s -> Coupe-circuit !
            if pwm_active and (time.time() - last_servo_move_time > 0.3):
                
                # 1. On coupe la fréquence
                lgpio.tx_pwm(h, GPIO_PIN, 0, 0)
                
                # 2. ⚡ On force la broche électriquement à 0 Volt (LOW)
                lgpio.gpio_write(h, GPIO_PIN, 0)
                
                pwm_active = False
                print("💤 Broche 18 forcée à LOW (Moteur totalement coupé)")

except KeyboardInterrupt:
    print("\n🛑 Arrêt demandé par l'utilisateur.")
except Exception as e:
    print(f"❌ Erreur inattendue : {e}")
finally:
    if arduino and arduino.is_open:
        arduino.close()
    lgpio.tx_pwm(h, GPIO_PIN, 0, 0)
    lgpio.gpio_free(h, GPIO_PIN)
    lgpio.gpiochip_close(h)
    print("✅ Port Série et Broches GPIO libérés. Fin du programme.")

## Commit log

2026-03-25 feat: test code servo
2026-03-25 config(servo): try angle
2026-03-25 fix(servo): script angle
2026-03-25 fix(servo): try reducing jitter
    [angles-servo.py]
2026-03-25 docs(servo): information about position function
2026-03-25 feat(camera): first codes to make the camera working
2026-03-26 feat(camera): first data batch test
2026-03-26 feat(camera): converted model
2026-03-26 feat(camera)&docs: added docs to manage all parts of the project
2026-03-26 fix(camera): filepath
2026-03-26 fix(camera): face recognition script
2026-03-26 fix(camera): test arduino control
2026-08-18 feat(ai-camera): person tracking from IMX500 to ESP32 eyes
    Add face_tracker.py: runs SSD MobileNetV2 on the IMX500 NPU, keeps the
    largest person box, estimates the head position and streams the mapped
    screen coordinates to the ESP32 at 115200 baud.
    The previous test script targeted a 320x240 screen at 9600 baud and read a
    non-existent 'ObjectDetect' metadata key, so it never produced a detection.
    Coordinates are now mapped to the round 240x240 GC9A01 and decoded through
    imx500.get_outputs / convert_inference_coords.
    Also fix a stray character in eyes_serial.ino that broke compilation.
    [eyes_serial.ino, face_tracker.py]
2026-08-18 feat(ai-camera): track faces with YOLOv8n-face on the IMX500
    Replace the COCO person detector with the exported YOLOv8n-face model, now
    packed to network.rpk and running on the sensor NPU at ~11 fps with 0.82
    confidence on a live face.
    Decoding the output needed two corrections that are not documented upstream:
    the boxes come out as [x0, y0, x1, y1] rather than picamera2's (y, x) order,
    and they are absolute pixels in the model's square 640x640 input, so the
    640x480 frame is letterboxed with 80 px bars. convert_inference_coords()
    assumes normalised boxes and returns garbage here, so the padding is removed
    and normalised by hand.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
    [face_tracker.py]
2026-08-18 docs(ai-camera): document the full install and bring-up procedure
    Rewrite the README as an ordered procedure: install, verify the hardware,
    pack the model onto the sensor, run the tracker.
    The verification section is deliberately split into independent checks. A
    model returning zero detections because the camera faces a wall looks exactly
    like a broken model, and coordinates reaching a serial port say nothing about
    the sketch on the other end, so each check isolates one link of the chain.
    Also record how to read the sensor output tensors, since the box ordering and
    the 640x640 letterboxing are not documented upstream, and ignore the
    generated rpk/ directory.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
2026-08-18 feat(ai-camera): add a 240x240 visualiser for the face tracker
    Show what the robot sees in a window the size of the eye screen, with the
    detected face and the position being sent to the ESP32 drawn on top. The
    visualiser drives the eye exactly like the tracker, so the preview explains
    the eye's behaviour while it happens instead of replacing it.
    The preview is mirrored so that it shares the frame of reference of the
    transmitted coordinates: the target dot can then be drawn at the position
    actually sent, which makes a mapping error immediately visible as a dot that
    misses the face.
    [face_tracker_visualizer.py]
2026-08-21 feat: code yaw pitch for cap robot
2026-08-21 fix: rename folder fot stl files for 3D body cap
    [Bottom Left Lid.stl, Bottom Lid Link (x2).stl, Bottom Right Lid.stl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]
